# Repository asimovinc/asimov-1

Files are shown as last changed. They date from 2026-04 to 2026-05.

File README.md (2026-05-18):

# Asimov v1: Open-Source Humanoid Robot




Asimov is an open-source humanoid robot that you can build, train and customize.

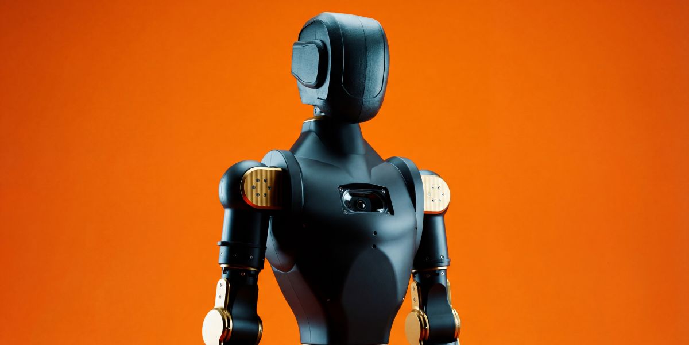
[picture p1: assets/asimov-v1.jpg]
Asimov v1

<p align="center">
  <a href="https://asimov.inc">Website</a> ·
  <a href="https://manual.asimov.inc">Manual</a> ·
  <a href="https://asimov.inc/diy-kit">DIY Kit</a> ·
  <a href="https://static.asimov.inc/asimov/v1/asimov-v1-20260420.html">3D Model</a> ·
  <a href="https://discord.gg/HzDfGN7kUw">Discord</a> ·
  <a href="https://x.com/asimovinc">X</a> ·
  <a href="https://forum.menlo.ai">Forum</a>
</p>

Asimov v1 is a 1.2 m, 35 kg biped with 25 actuated degrees of freedom. This repository contains the mechanical CAD, electrical CAD, simulation model, and onboard software to build, simulate, and customize Asimov v1.

---

## Specifications

| Spec | Value |
|---|---|
| Height | 1.2 m |
| Weight | 35 kg |
| Degrees of Freedom | 25 actuated + 2 passive |
| Legs | 6 DOF x 2 + toe x 2 |
| Arms | 5 DOF x 2 (shoulder pitch/roll/yaw, elbow, wrist yaw) |
| Torso | 1 DOF waist yaw, 10 W 4 ohm speaker, 6 DOF IMU |
| Head | 2 DOF neck (neck yaw, neck pitch), Quad microphone array, 2MP monocular camera |
| CAN Bus | 5 @ 1Mbps + 1 @ 500kbps |
| Onboard Compute | Raspberry Pi 5 (media + network) + Radxa CM5 (motion control) |
| Structural Materials | 7075 aluminium, MJF PA12 nylon |

| Activity | Load |
|---|---|
| Squat | 5 kg |
| Bicep curl | 15 kg each arm |
| Lateral raise | 18 kg each arm |

---

## Build your own Asimov

> [!TIP]
> **Option 1: DIY Kit:** Everything you need to build Asimov v1, unassembled. $499 deposit to reserve. $15,000 target price. Ships summer 2026. [Pre-order →](https://asimov.inc/diy-kit)

> [!NOTE]
> **Option 2: Self-source:** Pull the [BOM](https://manual.asimov.inc/v1/bom) and fabricate everything yourself. [Assembly Manual →](https://manual.asimov.inc)

### DIY Kit

| Category | Included | Not Included |
|---|---|---|
| Hardware | All BOM components (unassembled), power supply & cabling, spare parts | Tools, hands |
| Compute | RPi edge board, motion control board, network board, power distribution board | 4G/5G modules |
| Sensors | Monocular camera, IMUs, mic, speaker, motor joint states | Lidar, 360 cam |
| Safety | Wireless E-Stop, safety guidelines | Battery |
| Docs | Quick start guide, manual, DIY build videos | — |

**[Pre-order the Asimov v1 DIY Kit →](https://asimov.inc/diy-kit)**

### Self-source

Start with the repo-local [fabrication manifest](mechanical/FABRICATION_MANIFEST.csv) for the CAD-derived part inventory, then cross-reference the [BOM](https://manual.asimov.inc/v1/bom) and assembly manual for procurement details, sourcing, and fabrication notes.

**[Assembly Manual →](https://manual.asimov.inc)**

---

## Fabrication manifest

The CAD-derived fabrication manifest can be checked locally:

```bash
python3 scripts/generate_fabrication_manifest.py --check
```

---

## Roadmap

| Status | Item |
|---|---|
| ✅ | Mechanical CAD — 7 subassemblies |
| ✅ | MuJoCo simulation model |
| ✅ | Electrical wiring harness |
| ✅ | Electrical schematics & PCB files |
| 🔜 | Asimov API |
| 🔜 | Locomotion policy |
| 🔜 | Mobile app |

---

## Work with us

- **Build questions?**: Ask in the [forum](https://forum.menlo.ai) or open a [GitHub Issue](https://github.com/asimovinc/asimov-v1/issues) for bugs and contributions.
- **Deploying Asimov?**: [Talk to us →](mailto:bd@menlo.ai)
- **Supply chain partner?**: If you manufacture actuators, structural components, or electronics and want to be part of the Asimov supply chain, reach out.
[bd@menlo.ai](mailto:bd@menlo.ai)

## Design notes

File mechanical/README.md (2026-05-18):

# Mechanical Design

CAD for all 7 Asimov v1 subassemblies. STEP files, CNC aluminium parts, MJF nylon parts, and off-the-shelf hardware.

## Contents

```
mechanical/ASV1/
├── ASIMOV_V1.STEP          Full robot assembly
├── 100/ - 700/             Subassemblies
│   ├── ASV1_NNN.STEP       Subassembly STEP
│   └── FABRICATION/
│       ├── ALU_7075/       CNC-machined aluminium parts
│       ├── MJF_PA12/       3D-printed nylon parts (HP MJF)
│       └── OFF_THE_SHELF/  Standard hardware
└── NamingConvention.png    Part naming reference
```

`FABRICATION_MANIFEST.csv` and `FABRICATION_MANIFEST.json` are generated from the STEP files under `mechanical/ASV1/*/FABRICATION`. They provide the repo-local fabrication inventory for self-source builds and CI checks.

**[View the full assembly in your browser →](https://static.asimov.inc/asimov/v1/asimov-v1-20260420.html)**

## Validation

Regenerate or verify the fabrication manifest from the repository root:

```bash
python3 scripts/generate_fabrication_manifest.py
python3 scripts/generate_fabrication_manifest.py --check
```

## Naming Convention

Naming Convention

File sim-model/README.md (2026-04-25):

# Simulation Model

MuJoCo model for Asimov v1. 25 actuated joints, 28 link meshes, friction-tuned foot contacts. Built for locomotion policy training and hardware-in-the-loop testing.

## Contents

```
sim-model/
├── xmls/asimov.xml     Full robot model
└── assets/meshes/      28 STL link meshes
```

## Usage

```bash
python3 -m mujoco.viewer --mjcf=sim-model/xmls/asimov.xml
```

Requires [MuJoCo](https://mujoco.org/) 3.x.

## Resources

- [Locomotion Control guide](https://manual.asimov.inc/v1/locomotion) — policy training, control modes, and hardware-in-the-loop setup
- [Asimov API](https://github.com/asimovinc/asimov-api) — deploy policies to the real robot
- [Discord](https://discord.gg/HzDfGN7kUw) — questions and discussion

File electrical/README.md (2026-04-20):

## Wiring

WireViz was utilised for representing the wiring harness of the robot. 

Please refer to WireViz documentation for available visualisation options.
### Cable Naming Convention

```
W-<ID>-<TYPE>
ID = unique ID
TYPE = Power (PWR) or Signal (SIG) cable bundle
```

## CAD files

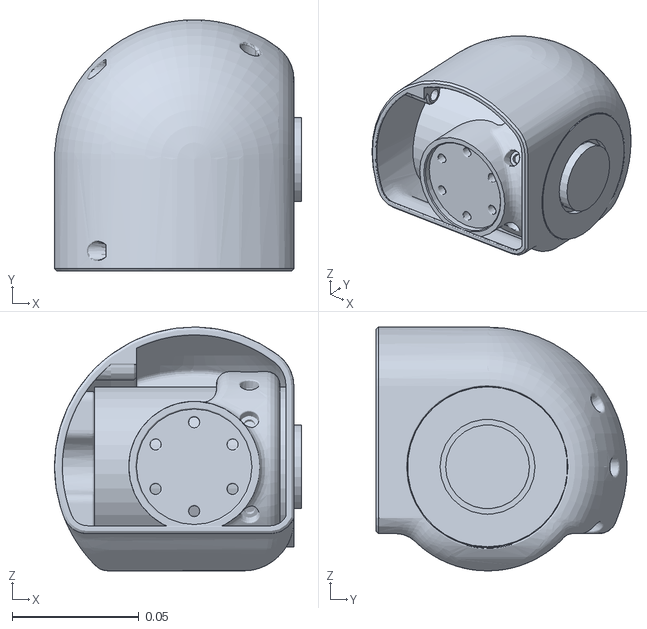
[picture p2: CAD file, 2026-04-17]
sim-model/assets/meshes/LEFT_HIP_PITCH.STL
0.0972 x 0.099 x 0.096

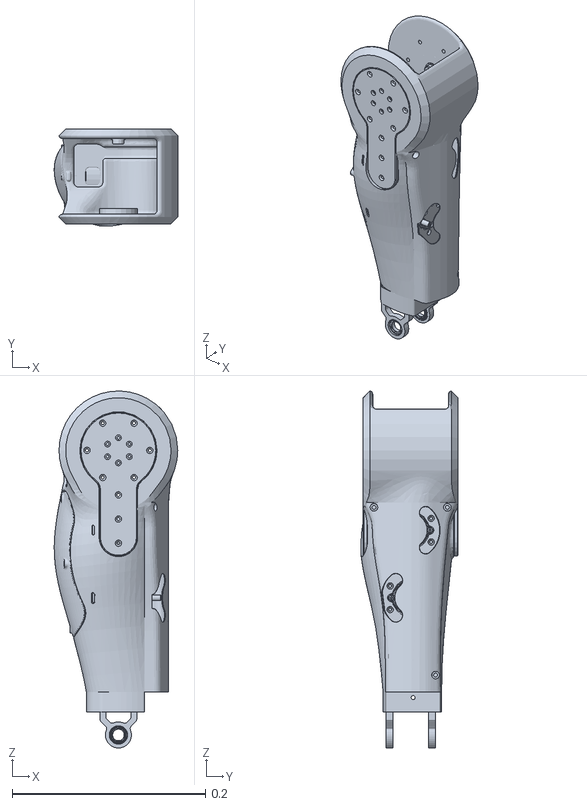
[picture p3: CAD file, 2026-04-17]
sim-model/assets/meshes/RIGHT_KNEE.STL
0.128 x 0.101 x 0.37

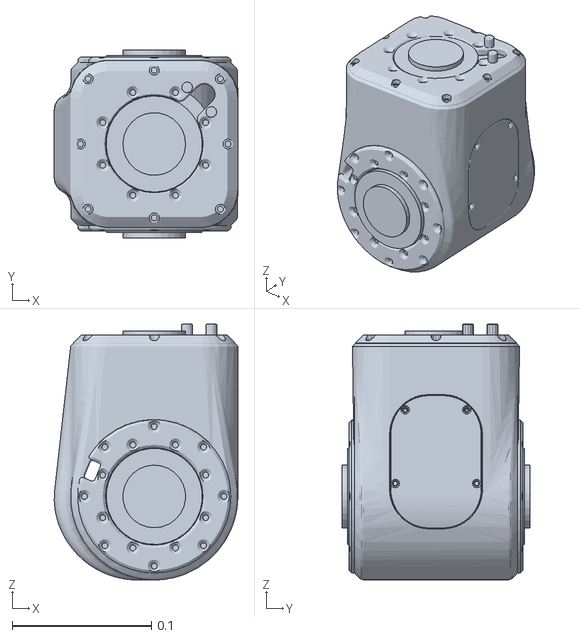
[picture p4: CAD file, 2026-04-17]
sim-model/assets/meshes/IMU_ORIGIN.STL
0.132 x 0.135 x 0.184

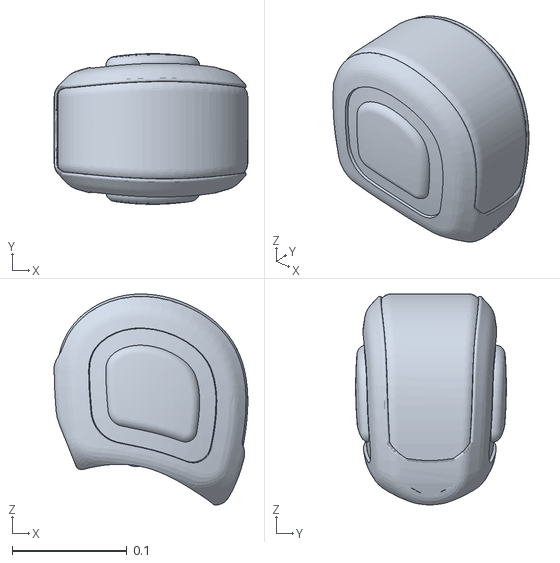
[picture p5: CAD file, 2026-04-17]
sim-model/assets/meshes/NECK_PITCH.STL
0.169 x 0.131 x 0.184

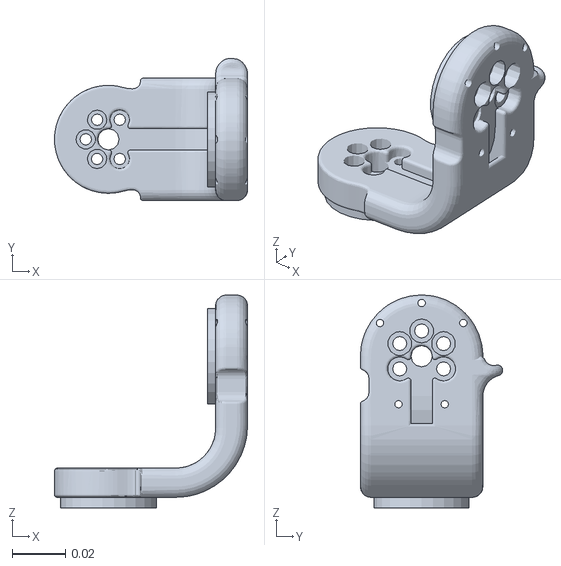
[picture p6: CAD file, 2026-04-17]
sim-model/assets/meshes/RIGHT_HIP_ROLL.STL
0.0725 x 0.0534 x 0.08

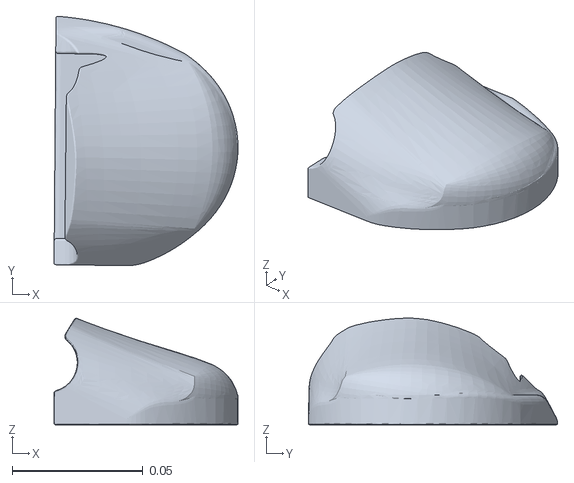
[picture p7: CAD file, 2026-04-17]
sim-model/assets/meshes/LEFT_TOE.STL
0.0703 x 0.0953 x 0.0407

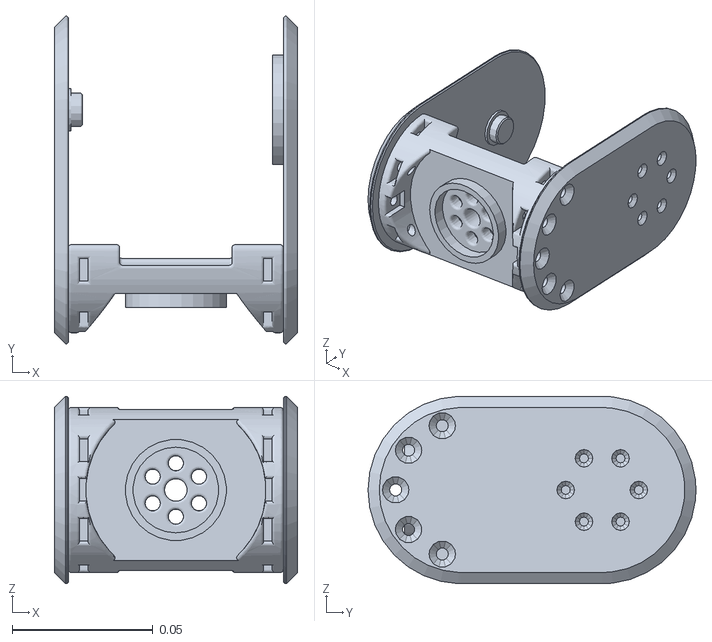
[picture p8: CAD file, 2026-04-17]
sim-model/assets/meshes/LEFT_SHOULDER_PITCH.STL
0.0866 x 0.117 x 0.0667

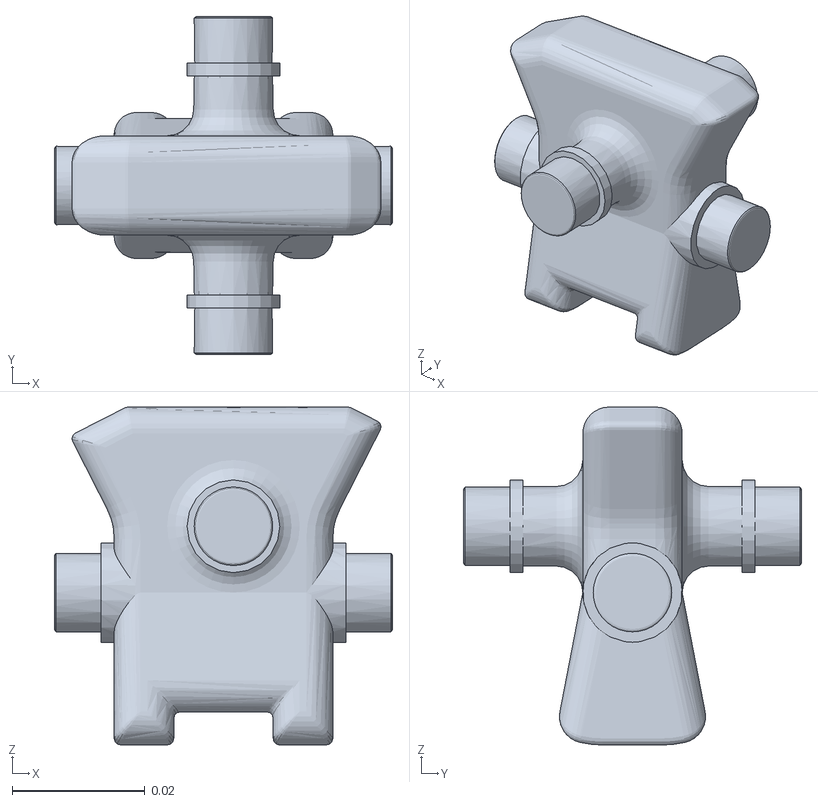
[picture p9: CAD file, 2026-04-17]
sim-model/assets/meshes/LEFT_ANKLE_A.STL
0.051 x 0.051 x 0.051

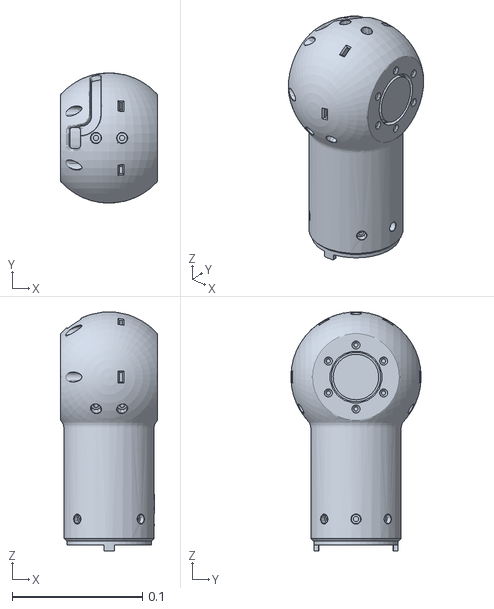
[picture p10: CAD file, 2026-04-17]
sim-model/assets/meshes/RIGHT_SHOULDER_ROLL.STL
0.0746 x 0.1 x 0.183

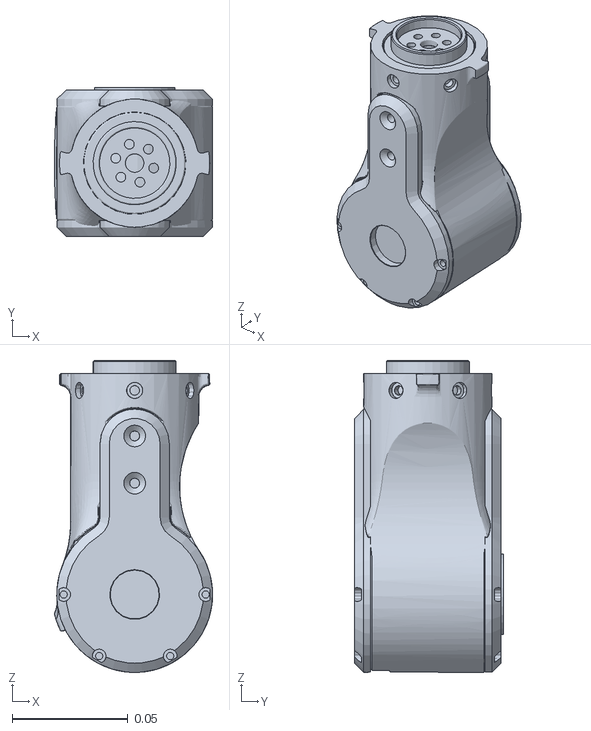
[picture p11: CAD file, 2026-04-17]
sim-model/assets/meshes/LEFT_SHOULDER_YAW.STL
0.0685 x 0.0645 x 0.135

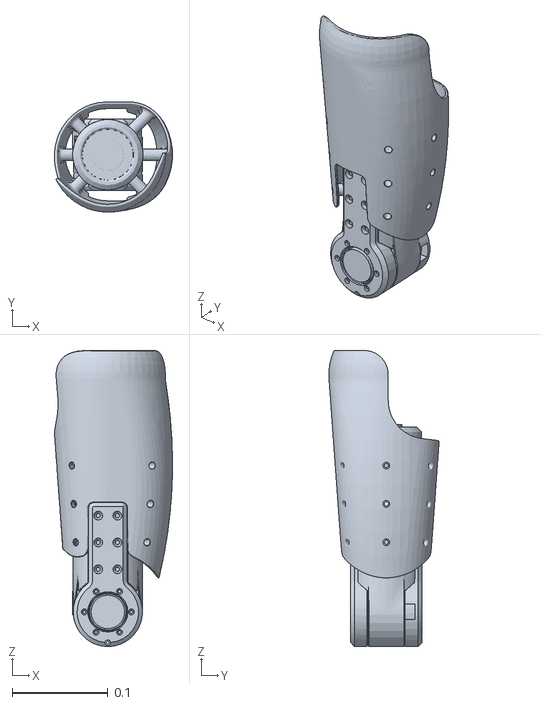
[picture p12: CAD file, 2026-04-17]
sim-model/assets/meshes/RIGHT_HIP_YAW.STL
0.123 x 0.115 x 0.309

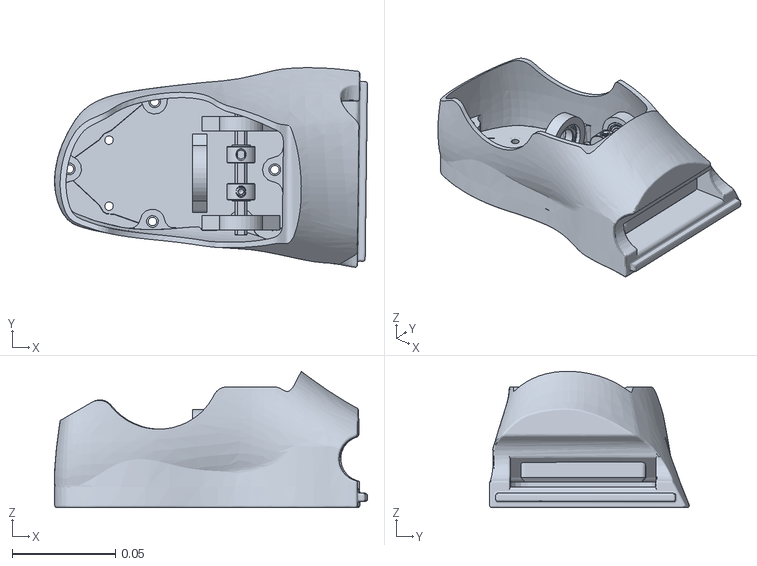
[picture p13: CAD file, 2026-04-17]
sim-model/assets/meshes/LEFT_ANKLE_B.STL
0.152 x 0.0968 x 0.0661

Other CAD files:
mechanical/ASV1/500/FABRICATION/MJF_PA12/ASV1_500_04C.STEP
mechanical/ASV1/600/FABRICATION/MJF_PA12/ASV1_600_14C.STEP
mechanical/ASV1/FullBodyAssembly/Asimov_1.STEP
mechanical/ASV1/500/FABRICATION/MJF_PA12/ASV1_500_14C.STEP
mechanical/ASV1/600/FABRICATION/MJF_PA12/ASV1_600_04C.STEP
sim-model/assets/meshes/RIGHT_ANKLE_A.STL
sim-model/assets/meshes/LEFT_ELBOW.STL
sim-model/assets/meshes/LEFT_HIP_ROLL.STL
sim-model/assets/meshes/LEFT_HIP_YAW.STL
sim-model/assets/meshes/LEFT_KNEE.STL
sim-model/assets/meshes/LEFT_SHOULDER_ROLL.STL
sim-model/assets/meshes/LEFT_WRIST_YAW.STL
sim-model/assets/meshes/NECK_YAW.STL
sim-model/assets/meshes/RIGHT_ELBOW.STL
sim-model/assets/meshes/RIGHT_HIP_PITCH.STL
sim-model/assets/meshes/RIGHT_SHOULDER_PITCH.STL
sim-model/assets/meshes/RIGHT_SHOULDER_YAW.STL
sim-model/assets/meshes/RIGHT_TOE.STL
sim-model/assets/meshes/RIGHT_WRIST_YAW.STL

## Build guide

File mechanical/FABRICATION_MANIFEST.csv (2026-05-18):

subassembly | fabrication_class | part_id | path
100 | ALU_7075 | ASV1_100_02A | mechanical/ASV1/100/FABRICATION/ALU_7075/ASV1_100_02A.STEP
100 | ALU_7075 | ASV1_100_03A | mechanical/ASV1/100/FABRICATION/ALU_7075/ASV1_100_03A.STEP
100 | MJF_PA12 | ASV1_100_01C | mechanical/ASV1/100/FABRICATION/MJF_PA12/ASV1_100_01C.STEP
100 | MJF_PA12 | ASV1_100_04C | mechanical/ASV1/100/FABRICATION/MJF_PA12/ASV1_100_04C.STEP
100 | MJF_PA12 | ASV1_100_05C | mechanical/ASV1/100/FABRICATION/MJF_PA12/ASV1_100_05C.STEP
100 | MJF_PA12 | ASV1_100_06C | mechanical/ASV1/100/FABRICATION/MJF_PA12/ASV1_100_06C.STEP
100 | MJF_PA12 | ASV1_100_10C | mechanical/ASV1/100/FABRICATION/MJF_PA12/ASV1_100_10C.STEP
100 | MJF_PA12 | ASV1_100_12C | mechanical/ASV1/100/FABRICATION/MJF_PA12/ASV1_100_12C.STEP
100 | OFF_THE_SHELF | ASV1_100_07X | mechanical/ASV1/100/FABRICATION/OFF_THE_SHELF/ASV1_100_07X.STEP
100 | OFF_THE_SHELF | ASV1_100_08X | mechanical/ASV1/100/FABRICATION/OFF_THE_SHELF/ASV1_100_08X.STEP
100 | OFF_THE_SHELF | ASV1_100_09X | mechanical/ASV1/100/FABRICATION/OFF_THE_SHELF/ASV1_100_09X.STEP
100 | OFF_THE_SHELF | ASV1_100_11X | mechanical/ASV1/100/FABRICATION/OFF_THE_SHELF/ASV1_100_11X.STEP
100 | OFF_THE_SHELF | ASV1_100_13X | mechanical/ASV1/100/FABRICATION/OFF_THE_SHELF/ASV1_100_13X.STEP
200 | ALU_7075 | ASV1_200_02A | mechanical/ASV1/200/FABRICATION/ALU_7075/ASV1_200_02A.STEP
200 | ALU_7075 | ASV1_200_03A | mechanical/ASV1/200/FABRICATION/ALU_7075/ASV1_200_03A.STEP
200 | ALU_7075 | ASV1_200_16A | mechanical/ASV1/200/FABRICATION/ALU_7075/ASV1_200_16A.STEP
200 | SML_316L | ASV1_200_04B | mechanical/ASV1/200/FABRICATION/SML_316L/ASV1_200_04B.STEP
200 | SML_316L | ASV1_200_05B | mechanical/ASV1/200/FABRICATION/SML_316L/ASV1_200_05B.STEP
200 | MJF_PA12 | ASV1_200_01C | mechanical/ASV1/200/FABRICATION/MJF_PA12/ASV1_200_01C.STEP
200 | MJF_PA12 | ASV1_200_06C | mechanical/ASV1/200/FABRICATION/MJF_PA12/ASV1_200_06C.STEP
200 | MJF_PA12 | ASV1_200_07C | mechanical/ASV1/200/FABRICATION/MJF_PA12/ASV1_200_07C.STEP
200 | MJF_PA12 | ASV1_200_08C | mechanical/ASV1/200/FABRICATION/MJF_PA12/ASV1_200_08C.STEP
200 | MJF_PA12 | ASV1_200_09C | mechanical/ASV1/200/FABRICATION/MJF_PA12/ASV1_200_09C.STEP
200 | MJF_PA12 | ASV1_200_15C | mechanical/ASV1/200/FABRICATION/MJF_PA12/ASV1_200_15C.STEP
200 | OFF_THE_SHELF | ASV1_200_10X | mechanical/ASV1/200/FABRICATION/OFF_THE_SHELF/ASV1_200_10X.STEP
200 | OFF_THE_SHELF | ASV1_200_11X | mechanical/ASV1/200/FABRICATION/OFF_THE_SHELF/ASV1_200_11X.STEP
200 | OFF_THE_SHELF | ASV1_200_12X | mechanical/ASV1/200/FABRICATION/OFF_THE_SHELF/ASV1_200_12X.STEP
200 | OFF_THE_SHELF | ASV1_200_13X | mechanical/ASV1/200/FABRICATION/OFF_THE_SHELF/ASV1_200_13X.STEP
200 | OFF_THE_SHELF | ASV1_200_14X | mechanical/ASV1/200/FABRICATION/OFF_THE_SHELF/ASV1_200_14X.STEP
300 | ALU_7075 | ASV1_300_01A | mechanical/ASV1/300/FABRICATION/ALU_7075/ASV1_300_01A.STEP
300 | ALU_7075 | ASV1_300_03A | mechanical/ASV1/300/FABRICATION/ALU_7075/ASV1_300_03A.STEP
300 | ALU_7075 | ASV1_300_05A | mechanical/ASV1/300/FABRICATION/ALU_7075/ASV1_300_05A.STEP
300 | ALU_7075 | ASV1_300_07A | mechanical/ASV1/300/FABRICATION/ALU_7075/ASV1_300_07A.STEP
300 | ALU_7075 | ASV1_300_08A | mechanical/ASV1/300/FABRICATION/ALU_7075/ASV1_300_08A.STEP
300 | ALU_7075 | ASV1_300_09A | mechanical/ASV1/300/FABRICATION/ALU_7075/ASV1_300_09A.STEP
300 | ALU_7075 | ASV1_300_10A | mechanical/ASV1/300/FABRICATION/ALU_7075/ASV1_300_10A.STEP
300 | ALU_7075 | ASV1_300_11A | mechanical/ASV1/300/FABRICATION/ALU_7075/ASV1_300_11A.STEP
300 | SML_316L | ASV1_300_02B | mechanical/ASV1/300/FABRICATION/SML_316L/ASV1_300_02B.STEP
300 | SML_316L | ASV1_300_04B | mechanical/ASV1/300/FABRICATION/SML_316L/ASV1_300_04B.STEP
300 | SML_316L | ASV1_300_06B | mechanical/ASV1/300/FABRICATION/SML_316L/ASV1_300_06B.STEP
300 | SML_316L | ASV1_300_12B | mechanical/ASV1/300/FABRICATION/SML_316L/ASV1_300_12B.STEP
300 | MJF_PA12 | ASV1_300_13C | mechanical/ASV1/300/FABRICATION/MJF_PA12/ASV1_300_13C.STEP
300 | MJF_PA12 | ASV1_300_14C | mechanical/ASV1/300/FABRICATION/MJF_PA12/ASV1_300_14C.STEP
300 | MJF_PA12 | ASV1_300_15C | mechanical/ASV1/300/FABRICATION/MJF_PA12/ASV1_300_15C.STEP
300 | MJF_PA12 | ASV1_300_16C | mechanical/ASV1/300/FABRICATION/MJF_PA12/ASV1_300_16C.STEP
300 | OFF_THE_SHELF | ASV1_300_17X | mechanical/ASV1/300/FABRICATION/OFF_THE_SHELF/ASV1_300_17X.STEP
300 | OFF_THE_SHELF | ASV1_300_18X | mechanical/ASV1/300/FABRICATION/OFF_THE_SHELF/ASV1_300_18X.STEP
300 | OFF_THE_SHELF | ASV1_300_19X | mechanical/ASV1/300/FABRICATION/OFF_THE_SHELF/ASV1_300_19X.STEP
300 | OFF_THE_SHELF | ASV1_300_20X | mechanical/ASV1/300/FABRICATION/OFF_THE_SHELF/ASV1_300_20X.STEP
300 | OFF_THE_SHELF | ASV1_300_21X | mechanical/ASV1/300/FABRICATION/OFF_THE_SHELF/ASV1_300_21X.STEP
300 | OFF_THE_SHELF | ASV1_300_22X | mechanical/ASV1/300/FABRICATION/OFF_THE_SHELF/ASV1_300_22X.STEP
300 | OFF_THE_SHELF | ASV1_300_23X | mechanical/ASV1/300/FABRICATION/OFF_THE_SHELF/ASV1_300_23X.STEP
400 | ALU_7075 | ASV1_400_04A | mechanical/ASV1/400/FABRICATION/ALU_7075/ASV1_400_04A.STEP
400 | ALU_7075 | ASV1_400_05A | mechanical/ASV1/400/FABRICATION/ALU_7075/ASV1_400_05A.STEP
400 | ALU_7075 | ASV1_400_11A | mechanical/ASV1/400/FABRICATION/ALU_7075/ASV1_400_11A.STEP
400 | ALU_7075 | ASV1_400_13A | mechanical/ASV1/400/FABRICATION/ALU_7075/ASV1_400_13A.STEP
400 | ALU_7075 | ASV1_400_14A | mechanical/ASV1/400/FABRICATION/ALU_7075/ASV1_400_14A.STEP
400 | ALU_7075 | ASV1_400_17A | mechanical/ASV1/400/FABRICATION/ALU_7075/ASV1_400_17A.STEP
400 | ALU_7075 | ASV1_400_18A | mechanical/ASV1/400/FABRICATION/ALU_7075/ASV1_400_18A.STEP
400 | ALU_7075 | ASV1_400_19A | mechanical/ASV1/400/FABRICATION/ALU_7075/ASV1_400_19A.STEP
400 | SML_316L | ASV1_400_02B | mechanical/ASV1/400/FABRICATION/SML_316L/ASV1_400_02B.STEP
400 | SML_316L | ASV1_400_03B | mechanical/ASV1/400/FABRICATION/SML_316L/ASV1_400_03B.STEP
400 | SML_316L | ASV1_400_12B | mechanical/ASV1/400/FABRICATION/SML_316L/ASV1_400_12B.STEP
400 | SML_316L | ASV1_400_20B | mechanical/ASV1/400/FABRICATION/SML_316L/ASV1_400_20B.STEP
400 | MJF_PA12 | ASV1_400_06C | mechanical/ASV1/400/FABRICATION/MJF_PA12/ASV1_400_06C.STEP
400 | MJF_PA12 | ASV1_400_07C | mechanical/ASV1/400/FABRICATION/MJF_PA12/ASV1_400_07C.STEP
400 | MJF_PA12 | ASV1_400_15C | mechanical/ASV1/400/FABRICATION/MJF_PA12/ASV1_400_15C.step
400 | MJF_PA12 | ASV1_400_16C | mechanical/ASV1/400/FABRICATION/MJF_PA12/ASV1_400_16C.step
400 | OFF_THE_SHELF | ASV1_400_01X | mechanical/ASV1/400/FABRICATION/OFF_THE_SHELF/ASV1_400_01X.STEP
400 | OFF_THE_SHELF | ASV1_400_08X | mechanical/ASV1/400/FABRICATION/OFF_THE_SHELF/ASV1_400_08X.STEP
400 | OFF_THE_SHELF | ASV1_400_09X | mechanical/ASV1/400/FABRICATION/OFF_THE_SHELF/ASV1_400_09X.STEP
400 | OFF_THE_SHELF | ASV1_400_10X | mechanical/ASV1/400/FABRICATION/OFF_THE_SHELF/ASV1_400_10X.STEP
400 | OFF_THE_SHELF | ASV1_400_21X | mechanical/ASV1/400/FABRICATION/OFF_THE_SHELF/ASV1_400_21X.STEP
400 | OFF_THE_SHELF | ASV1_400_22X | mechanical/ASV1/400/FABRICATION/OFF_THE_SHELF/ASV1_400_22X.STEP
400 | OFF_THE_SHELF | ASV1_400_23X | mechanical/ASV1/400/FABRICATION/OFF_THE_SHELF/ASV1_400_23X.STEP
500 | ALU_7075 | ASV1_500_05A | mechanical/ASV1/500/FABRICATION/ALU_7075/ASV1_500_05A.STEP
500 | ALU_7075 | ASV1_500_06A | mechanical/ASV1/500/FABRICATION/ALU_7075/ASV1_500_06A.STEP
500 | ALU_7075 | ASV1_500_08A | mechanical/ASV1/500/FABRICATION/ALU_7075/ASV1_500_08A.STEP
500 | ALU_7075 | ASV1_500_09A | mechanical/ASV1/500/FABRICATION/ALU_7075/ASV1_500_09A.STEP
500 | ALU_7075 | ASV1_500_12A | mechanical/ASV1/500/FABRICATION/ALU_7075/ASV1_500_12A.STEP
500 | ALU_7075 | ASV1_500_23A_SS | mechanical/ASV1/500/FABRICATION/ALU_7075/ASV1_500_23A_SS.STEP
500 | ALU_7075 | ASV1_500_24A_SS | mechanical/ASV1/500/FABRICATION/ALU_7075/ASV1_500_24A_SS.STEP
500 | ALU_7075 | ASV1_500_25A | mechanical/ASV1/500/FABRICATION/ALU_7075/ASV1_500_25A.STEP
500 | ALU_7075 | ASV1_500_36A | mechanical/ASV1/500/FABRICATION/ALU_7075/ASV1_500_36A.STEP
500 | SML_316L | ASV1_500_01B | mechanical/ASV1/500/FABRICATION/SML_316L/ASV1_500_01B.STEP
500 | SML_316L | ASV1_500_17B | mechanical/ASV1/500/FABRICATION/SML_316L/ASV1_500_17B.STEP
500 | SML_316L | ASV1_500_18B | mechanical/ASV1/500/FABRICATION/SML_316L/ASV1_500_18B.STEP
500 | SML_316L | ASV1_500_26B | mechanical/ASV1/500/FABRICATION/SML_316L/ASV1_500_26B.STEP
500 | MJF_PA12 | ASV1_500_03C | mechanical/ASV1/500/FABRICATION/MJF_PA12/ASV1_500_03C.STEP
500 | MJF_PA12 | ASV1_500_04C | mechanical/ASV1/500/FABRICATION/MJF_PA12/ASV1_500_04C.STEP
500 | MJF_PA12 | ASV1_500_10C | mechanical/ASV1/500/FABRICATION/MJF_PA12/ASV1_500_10C.STEP
500 | MJF_PA12 | ASV1_500_13C | mechanical/ASV1/500/FABRICATION/MJF_PA12/ASV1_500_13C.STEP
500 | MJF_PA12 | ASV1_500_14C | mechanical/ASV1/500/FABRICATION/MJF_PA12/ASV1_500_14C.STEP
500 | MJF_PA12 | ASV1_500_37C | mechanical/ASV1/500/FABRICATION/MJF_PA12/ASV1_500_37C.STEP
500 | MJF_PA12 | ASV1_500_38C | mechanical/ASV1/500/FABRICATION/MJF_PA12/ASV1_500_38C.STEP
500 | MJF_PA12 | ASV1_500_39C | mechanical/ASV1/500/FABRICATION/MJF_PA12/ASV1_500_39C.STEP
500 | MJF_PA12 | ASV1_500_40C | mechanical/ASV1/500/FABRICATION/MJF_PA12/ASV1_500_40C.STEP
500 | OFF_THE_SHELF | ASV1_500_02X | mechanical/ASV1/500/FABRICATION/OFF_THE_SHELF/ASV1_500_02X.STEP
500 | OFF_THE_SHELF | ASV1_500_07X | mechanical/ASV1/500/FABRICATION/OFF_THE_SHELF/ASV1_500_07X.STEP
500 | OFF_THE_SHELF | ASV1_500_11X | mechanical/ASV1/500/FABRICATION/OFF_THE_SHELF/ASV1_500_11X.STEP
500 | OFF_THE_SHELF | ASV1_500_15X | mechanical/ASV1/500/FABRICATION/OFF_THE_SHELF/ASV1_500_15X.STEP
500 | OFF_THE_SHELF | ASV1_500_16X | mechanical/ASV1/500/FABRICATION/OFF_THE_SHELF/ASV1_500_16X.STEP
500 | OFF_THE_SHELF | ASV1_500_19X | mechanical/ASV1/500/FABRICATION/OFF_THE_SHELF/ASV1_500_19X.STEP
500 | OFF_THE_SHELF | ASV1_500_20X | mechanical/ASV1/500/FABRICATION/OFF_THE_SHELF/ASV1_500_20X.STEP
500 | OFF_THE_SHELF | ASV1_500_21X | mechanical/ASV1/500/FABRICATION/OFF_THE_SHELF/ASV1_500_21X.STEP
500 | OFF_THE_SHELF | ASV1_500_22X | mechanical/ASV1/500/FABRICATION/OFF_THE_SHELF/ASV1_500_22X.STEP
500 | OFF_THE_SHELF | ASV1_500_27X | mechanical/ASV1/500/FABRICATION/OFF_THE_SHELF/ASV1_500_27X.STEP
500 | OFF_THE_SHELF | ASV1_500_28X | mechanical/ASV1/500/FABRICATION/OFF_THE_SHELF/ASV1_500_28X.STEP
500 | OFF_THE_SHELF | ASV1_500_29X | mechanical/ASV1/500/FABRICATION/OFF_THE_SHELF/ASV1_500_29X.STEP
500 | OFF_THE_SHELF | ASV1_500_30X | mechanical/ASV1/500/FABRICATION/OFF_THE_SHELF/ASV1_500_30X.STEP
500 | OFF_THE_SHELF | ASV1_500_31X | mechanical/ASV1/500/FABRICATION/OFF_THE_SHELF/ASV1_500_31X.STEP
500 | OFF_THE_SHELF | ASV1_500_32X | mechanical/ASV1/500/FABRICATION/OFF_THE_SHELF/ASV1_500_32X.STEP
500 | OFF_THE_SHELF | ASV1_500_33X | mechanical/ASV1/500/FABRICATION/OFF_THE_SHELF/ASV1_500_33X.STEP
500 | OFF_THE_SHELF | ASV1_500_34X | mechanical/ASV1/500/FABRICATION/OFF_THE_SHELF/ASV1_500_34X.STEP
500 | OFF_THE_SHELF | ASV1_500_35X | mechanical/ASV1/500/FABRICATION/OFF_THE_SHELF/ASV1_500_35X.STEP
500 | OFF_THE_SHELF | ASV1_500_41X | mechanical/ASV1/500/FABRICATION/OFF_THE_SHELF/ASV1_500_41X.STEP
600 | ALU_7075 | ASV1_600_05A | mechanical/ASV1/600/FABRICATION/ALU_7075/ASV1_600_05A.step.STEP
600 | ALU_7075 | ASV1_600_06A | mechanical/ASV1/600/FABRICATION/ALU_7075/ASV1_600_06A.step.STEP
600 | ALU_7075 | ASV1_600_08A | mechanical/ASV1/600/FABRICATION/ALU_7075/ASV1_600_08A.step.STEP
600 | ALU_7075 | ASV1_600_09A | mechanical/ASV1/600/FABRICATION/ALU_7075/ASV1_600_09A.step.STEP
600 | ALU_7075 | ASV1_600_12A | mechanical/ASV1/600/FABRICATION/ALU_7075/ASV1_600_12A.step.STEP
600 | ALU_7075 | ASV1_600_23A_SS | mechanical/ASV1/600/FABRICATION/ALU_7075/ASV1_600_23A_SS.step.STEP
600 | ALU_7075 | ASV1_600_24A_SS | mechanical/ASV1/600/FABRICATION/ALU_7075/ASV1_600_24A_SS.step.STEP
600 | ALU_7075 | ASV1_600_25A | mechanical/ASV1/600/FABRICATION/ALU_7075/ASV1_600_25A.step.STEP
600 | ALU_7075 | ASV1_600_36A | mechanical/ASV1/600/FABRICATION/ALU_7075/ASV1_600_36A.step.STEP
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

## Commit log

2026-04-17 add sim-model assets and xml
    [IMU_ORIGIN.STL, LEFT_ANKLE_A.STL, LEFT_ANKLE_B.STL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]
2026-04-20 Prepare electrical information for release, misc changes (#1)
    * added wiring, added software license
    * updated README
2026-05-18 Add fabrication manifest artifact checks (#5)
    * Add fabrication manifest artifact checks
    * Simplify fabrication manifest checks
    ---------
    [FABRICATION_MANIFEST.csv]
2026-10-06 Update latest Asimov v1 CAD files (#27)
    Update 500/600 04C and 14C parts and FullBodyAssembly STEP.
    [ASV1_500_04C.STEP, ASV1_500_14C.STEP, ASV1_600_04C.STEP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]

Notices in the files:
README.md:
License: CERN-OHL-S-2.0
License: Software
